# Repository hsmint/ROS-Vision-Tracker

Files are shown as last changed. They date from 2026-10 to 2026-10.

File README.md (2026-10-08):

<div align="center">

# ROS-Vision-Tracker

### See the cube. Follow the motion.

A depth-aware, two-axis camera tracker built with ROS 2 and Raspberry Pi.

**KANT PA 1기 · Project 1 · Team Xmen**






**[Quick start](#quick-start)** · **[Architecture](#architecture)** · **[Demo](#demo)** · **[Performance](#performance-snapshot)** · **[Documentation](#documentation)** · **[Releases](https://github.com/hsmint/ROS-Vision-Tracker/releases)**

</div>

---

ROS-Vision-Tracker finds a blue cube and keeps it in view. An Intel RealSense camera captures
color and aligned depth on a Raspberry Pi; the tracker checks color, physical
size, and shape, then bridges brief occlusions with CSRT. An OpenCR board drives
two DYNAMIXEL servos to aim the camera. An optional remote PC displays the
annotated image and robot model in RViz2.

## Highlights

| 🔎 Depth-aware detection | 🎯 Pan & tilt tracking | 🖥️ Remote visualization |
| :--- | :--- | :--- |
| HSV color, real-world size, and shape checks help select the blue cube. | Independent velocity commands drive two axes, with automatic homing on startup. | Annotated JPEG preview and an RViz2 robot model keep tracking visible from a second machine. |

| 🧩 Occlusion handling | 📼 Record & replay | 🍓 Runs on the Pi |
| :--- | :--- | :--- |
| CSRT bridges brief gaps in detection. | Replay synchronized color and depth bags for offline analysis. | Capture, tracking, and control continue without a remote PC. |

## Architecture

```mermaid
flowchart LR
    subgraph PI["Raspberry Pi · ROS 2"]
        CAMERA["RealSense capture"]
        TRACKER["Cube detector + tracker"]
        CONTROL["OpenCR serial driver"]
        PREVIEW["JPEG preview"]
        CAMERA -->|"RGB + aligned depth"| TRACKER
        TRACKER -->|"/cmd_vel"| CONTROL
        CAMERA -->|"Color frames"| PREVIEW
        TRACKER -->|"/tracking/bbox"| PREVIEW
    end

    CONTROL -->|"Serial"| OPENCR["OpenCR"]
    OPENCR --> MOTORS["DYNAMIXEL · pan + tilt"]
    PREVIEW -->|"Annotated JPEG"| PC["Remote PC · RViz2"]

    classDef vision fill:#e0f2fe,stroke:#0284c7,color:#0c4a6e
    classDef motion fill:#dcfce7,stroke:#16a34a,color:#14532d
    classDef display fill:#f3e8ff,stroke:#9333ea,color:#581c87
    class CAMERA,TRACKER vision
    class CONTROL,OPENCR,MOTORS motion
    class PREVIEW,PC display
```

The default launch targets **30 Hz image publication**, **20 Hz tracking**, and
**20 Hz commands**. The separate JPEG preview targets **5 Hz**. These are
configured rates; see [Performance](#performance-snapshot) for measured performance and limits.

| Package | Responsibility |
| :--- | :--- |
| [`xmen_tracker`](xmen_tracker/) | RealSense capture, cube detection/tracking, velocity commands, JPEG preview, RViz overlays |
| [`xmen_control`](xmen_control/) | OpenCR serial driver (`control_lite`) and `/joint_states` publication |
| [`xmen_bringup`](xmen_bringup/) | Hardware and remote visualization launch files |
| [`xmen_description`](xmen_description/) | Pan/tilt URDF, CAD meshes, and RViz configuration |
| [`firmware`](firmware/) | OpenCR source and prebuilt ARM64 flashing bundle |

## Demo

<div align="center">

### 🎬 See ROS-Vision-Tracker in action

</div>

#### 🎯 Real-world tracking

https://github.com/user-attachments/assets/06dc1db3-719f-4d2d-9c7e-61715f263b9c

#### 🖥️ Inside RViz2

https://github.com/user-attachments/assets/06f8cf11-2dbd-4d1b-b99b-0d997ce7b2b6

## Prerequisites

### Hardware

- Raspberry Pi running **64-bit Ubuntu 26.04 (ARM64)**
- Intel RealSense depth camera (D435 or similar), connected over USB 3
- ROBOTIS OpenCR 1.0 with two DYNAMIXEL XM430-W350 servos (pan ID 11, tilt ID 12)
- A blue cube target (about 5 cm)
- Optional: a PC on the same network for RViz2 visualization

### Software

- [ROS 2 Lyrical](https://docs.ros.org/en/lyrical/Installation/Ubuntu-Install-Debs.html), installed at `/opt/ros/lyrical`
- [RealSense SDK Python bindings (`pyrealsense2`)](https://github.com/realsenseai/librealsense)
  for the system Python, plus its USB rules. rosdep does not install this one; see
  [camera package](xmen_tracker/).
- Serial port access for your user (for flashing and for `control_lite`):

  ```bash
  sudo usermod -aG dialout $USER   # then log out and back in
  ```

### Firmware

The prebuilt firmware in [`firmware/opencr.tar.gz`](firmware/opencr.tar.gz)
needs no extra tools. Its flasher, `opencr_ld`, is an ARM64 Linux binary that
only depends on the C library, so it runs on the Pi as is. Flashing from an
x86 PC is not supported with this archive.

Only if you change [`opencr_lite.ino`](firmware/opencr_lite.ino): Arduino IDE
with the [OpenCR board package](https://emanual.robotis.com/docs/en/parts/controller/opencr10/#arduino-ide)
and the `Dynamixel2Arduino` library.

<details>
<summary><strong>Package dependency reference</strong></summary>

These are declared in each `package.xml`; `rosdep` installs them.

| Package | Dependencies |
|---|---|
| `xmen_tracker` | `rclpy`, `sensor_msgs`, `geometry_msgs`, `std_msgs`, `visualization_msgs`, `message_filters`, `cv_bridge`, `tf2_ros_py`, `rcl_interfaces`, `launch`, `launch_ros`, `python3-numpy`, `python3-opencv`, `python3-yaml` |
| `xmen_control` | `rclpy`, `geometry_msgs`, `sensor_msgs`, `python3-serial`, `dynamixel_sdk` |
| `xmen_bringup` | `launch`, `launch_ros`, `rviz2`, `robot_state_publisher`, `joint_state_publisher`, `tf2_ros`, `ros2bag`, `rosbag2_transport`, `rosbag2_storage_default_plugins` |
| `xmen_description` | none (URDF and meshes only) |

</details>

## Quick start

### 1 · Flash the OpenCR

[`firmware/opencr.tar.gz`](firmware/opencr.tar.gz) contains the prebuilt
firmware (`opencr_lite.opencr`) and the flasher (`opencr_ld`, built for ARM64,
so run it on the Pi). Connect the OpenCR over USB, then find its port:

```bash
ls /dev/ttyACM*            # usually /dev/ttyACM0
```

Extract the archive and flash the firmware:

```bash
# From the repository root on the Pi
cd firmware
tar -xf opencr.tar.gz
PORT=/dev/ttyACM0          # the port found above
./opencr_ld $PORT 115200 opencr_lite.opencr
```

If the port gives "permission denied", check the `dialout` prerequisite above.

`control_lite` only works with this firmware. To change it, edit
[`firmware/opencr_lite.ino`](firmware/opencr_lite.ino) and rebuild it in the
Arduino IDE.

### 2 · Set up the Raspberry Pi

Option A uses a prebuilt release and needs no build. Option B builds from source.

<details open>
<summary><strong>Option A · Install a prebuilt release</strong></summary>

Download the `.tar.gz` and `.sha256` from
[Releases](https://github.com/hsmint/ROS-Vision-Tracker/releases):

```bash
# Replace v1.0.0 with the downloaded release version.
sha256sum -c xmen-v1.0.0-ubuntu-26.04-ros-lyrical-arm64.tar.gz.sha256
mkdir -p ~/xmen-v1.0.0
tar -xzf xmen-v1.0.0-ubuntu-26.04-ros-lyrical-arm64.tar.gz -C ~/xmen-v1.0.0
cd ~/xmen-v1.0.0

# One-time: install ROS/system dependencies
sudo apt-get install python3-rosdep
sudo rosdep init   # only if rosdep is not initialized yet
rosdep update --rosdistro lyrical
rosdep install --from-paths dependencies --ignore-src --rosdistro lyrical -y

. install/setup.bash
python3 check-runtime.py   # checks imports; does not open the camera or move motors
```

Extract each new release into a fresh directory to avoid stale files.

</details>

<details>
<summary><strong>Option B · Build from source</strong></summary>

```bash
mkdir -p ~/xmen_ws/src && cd ~/xmen_ws/src
git clone https://github.com/hsmint/ROS-Vision-Tracker.git Xmen
cd ~/xmen_ws
source /opt/ros/lyrical/setup.bash
rosdep install --from-paths src --ignore-src -r -y
colcon build --symlink-install --packages-up-to xmen_bringup
source install/setup.bash
```

</details>

### 3 · Start tracking

On the **Pi**:

```bash
export ROS_DOMAIN_ID=50   # use the same value on both machines
ros2 launch xmen_bringup hardware_launch.py
```

> [!IMPORTANT]
> The motors home on startup, then the camera follows the cube. Use
> `start_control:=false` to run the camera and tracker without moving the motors.

Useful options:

```bash
ros2 launch xmen_bringup hardware_launch.py port:=/dev/ttyACM0      # choose a serial port
ros2 launch xmen_bringup hardware_launch.py start_control:=false   # track without moving motors
ros2 launch xmen_bringup hardware_launch.py image_hz:=15.0         # lower CPU load
```

On the **remote PC** (optional, build from source as in 2B):

```bash
export ROS_DOMAIN_ID=50   # use the same value on both machines
ros2 launch xmen_bringup rviz2_launch.py
```

Both machines must use the same `ROS_DOMAIN_ID` and be able to reach each other
over the network. Tracking keeps running without the PC.

Check the tracker from either machine:

```bash
ros2 topic echo /perception_status   # OK, NO_TARGET, or CAMERA_STALL
ros2 topic echo /target --qos-reliability best_effort
```

To record and replay rosbags, use the RViz options, or set serial-port
overrides, see the [bringup package](xmen_bringup/). To tune
detection, see [xmen_tracker](xmen_tracker/) and
[PERCEPTION.md](lv2_module5/results/PERCEPTION.md).

## Documentation

| I want to… | Read this |
| :--- | :--- |
| Configure launch options, remote RViz, or bag playback | [Bringup package](xmen_bringup/) |
| Understand tracker nodes, topics, and commands | [Tracker package](xmen_tracker/) |
| Tune detection or evaluate recordings | [Perception guide](lv2_module5/results/PERCEPTION.md) |
| Set up the camera and Python bindings | [Camera package](xmen_tracker/) |
| Inspect the robot model and meshes | [Robot description](xmen_description/) |
| Modify the OpenCR firmware | [Firmware source](firmware/opencr_lite.ino) |

## Performance Snapshot

**Raspberry Pi 4** · 640×360 RGB + depth · 60-second sample

| 📷 RGB / Depth | 🎯 Tracking | ⚙️ Commands | 🖥️ Preview |
| :---: | :---: | :---: | :---: |
| **25.85 / 25.86 FPS** | **12.66 Hz** | **13.59 Hz** | **2.00 FPS** |

**Tracker status:** `OK` throughout the sample

## Contributors

<div align="center">

### Team Xmen

ROS-Vision-Tracker was developed as **Project 1 for KANT PA 1기**.

<table>
  <tr>
    <td align="center" width="25%">
      <a href="https://github.com/hsmint">
        SeokMin Hong GitHub profile
      </a>
      <br /><br />
      <strong>SeokMin Hong</strong>
      <br />
      <a href="https://github.com/hsmint">@hsmint</a>
    </td>
    <td align="center" width="25%">
      <a href="https://github.com/chj1319">
        최형준 GitHub profile
      </a>
      <br /><br />
      <strong>최형준</strong>
      <br />
      <a href="https://github.com/chj1319">@chj1319</a>
    </td>
    <td align="center" width="25%">
      <a href="https://github.com/heffeekim94-web">
        김혜민 GitHub profile
      </a>
      <br /><br />
      <strong>김혜민</strong>
      <br />
      <a href="https://github.com/heffeekim94-web">@heffeekim94-web</a>
    </td>
    <td align="center" width="25%">
      <a href="https://github.com/kanichong">
        이홍주 GitHub profile
      </a>
      <br /><br />
      <strong>이홍주</strong>
      <br />
      <a href="https://github.com/kanichong">@kanichong</a>
    </td>
  </tr>
</table>

</div>

---

<div align="center">

**[Get started](#quick-start)** · **[Explore the docs](#documentation)** · **[Back to top](#ros-vision-tracker)**

</div>

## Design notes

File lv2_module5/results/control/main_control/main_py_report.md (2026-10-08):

# main.py 코드 설명 보고서

2026-10-03 · pa06

## 개요

main.py는 라즈베리파이에서 키보드로 입력한 명령을 USB 시리얼로 OpenCR 보드에 보내고, 보드가 보낸 답을 화면에 출력하는 63줄짜리 프로그램입니다. 모터를 직접 움직이지는 않습니다. 명령 해석, 범위 검사, 모터 제어는 모두 OpenCR 펌웨어(opencr_control.ino)가 맡습니다.

프로그램은 두 방향의 데이터를 동시에 처리합니다.
- **보내는 방향:** 키보드 입력 → `send_command()` → USB → OpenCR
- **받는 방향:** OpenCR의 `Serial.println()` → USB → 반복 루프의 수신 부분 → 화면

두 방향을 하나의 반복문에서 번갈아 확인할 수 있는 이유는 `select`가 키보드와 보드 중 데이터가 도착한 쪽을 알려 주기 때문입니다. 그래서 모터가 움직이는 동안에도 보드 메시지를 계속 보여 주면서 새 명령(예: `x` 정지)을 받을 수 있습니다.

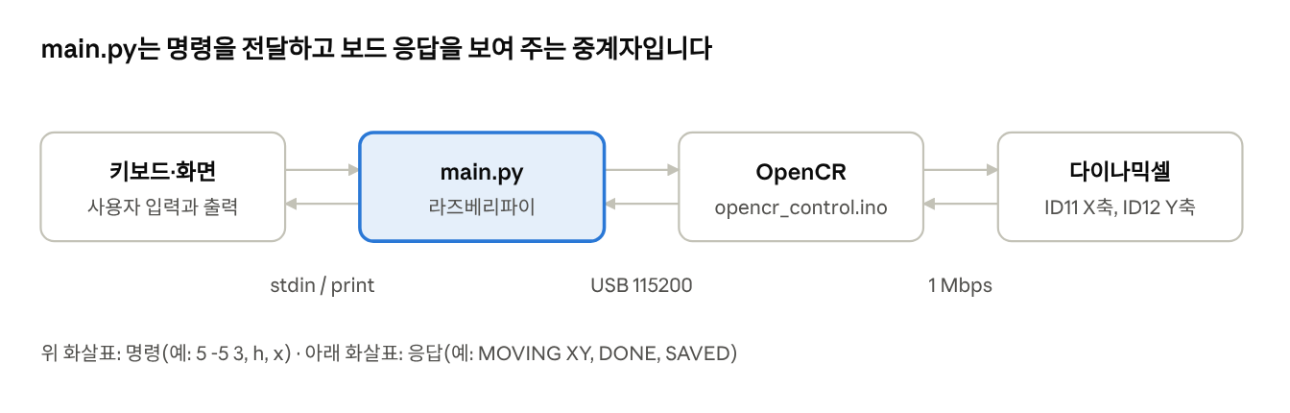
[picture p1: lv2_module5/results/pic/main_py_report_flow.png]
데이터 흐름 · 4단계, 양방향


*데이터 흐름 · 4단계, 양방향*

명령은 왼쪽에서 오른쪽으로, 응답은 오른쪽에서 왼쪽으로 흐릅니다. main.py는 가운데에서 글자를 전달만 합니다.

## 1~13줄: 준비물과 설정값

파일 맨 위에서 필요한 도구를 불러오고, 통신 설정과 사용법 안내문을 정합니다.

| 줄 | 코드 | 뜻 |
|---|---|---|
| 1 | `"""..."""` | 파일 설명문입니다. 실행에는 영향이 없습니다. |
| 2 | `import select` | 키보드와 보드 중 어느 쪽에 새 데이터가 왔는지 동시에 지켜보는 도구입니다. |
| 3 | `import sys` | 키보드 입력(`sys.stdin`), 오류 출력, 프로그램 종료에 씁니다. |
| 4 | `import time` | 기다리기(`time.sleep`)에 씁니다. |
| 6 | `import serial` | USB 시리얼 통신 라이브러리(pyserial)입니다. OpenCR과 대화하는 데 씁니다. |
| 8 | `PORT = "/dev/ttyACM0"` | OpenCR이 연결된 USB 장치 이름입니다. |
| 9 | `BAUDRATE = 115200` | 통신 속도입니다. 펌웨어의 `Serial.begin(115200)`과 반드시 같아야 합니다. |
| 10~13 | `HELP = """..."""` | 사용법 안내문입니다. 시작할 때와 `help`를 입력했을 때 출력됩니다. |

`import serial`만 빈 줄로 떨어져 있는 이유는 파이썬 관례 때문입니다. 기본 내장 모듈(select, sys, time)과 따로 설치한 모듈(serial)을 나눠 적습니다.

## 16~18줄: send_command(), 보드로 명령 보내기

입력한 글자를 보드가 알아듣는 형식으로 바꿔 한 줄 단위로 보냅니다.

```python
def send_command(board, command):
    board.write((command.strip() + "\n").encode("ascii"))
    board.flush()
```

- **16줄:** `board`는 열려 있는 시리얼 포트, `command`는 보낼 글자입니다.
- **17줄:** 세 단계를 한 줄에서 처리합니다.
  - `strip()`: 앞뒤 공백을 지웁니다.
  - `+ "\n"`: 끝에 줄바꿈을 붙입니다. OpenCR은 줄바꿈을 받아야 명령 한 줄이 끝났다고 판단합니다.
  - `encode("ascii")`: 글자를 바이트로 바꿉니다. 한글처럼 ASCII가 아닌 글자가 있으면 `UnicodeEncodeError`가 납니다.
- **18줄:** `flush()`로 모아 둔 데이터를 즉시 내보냅니다.

## 21~27줄: main() 연결 준비

포트를 열고 보드가 준비될 때까지 기다린 뒤, 사용법을 보여 주는 단계입니다.

| 줄 | 코드 | 뜻 |
|---|---|---|
| 21 | `def main():` | 프로그램 본체 함수입니다. |
| 22 | `with serial.Serial(...) as board:` | 시리얼 포트를 엽니다. `with`를 쓰면 프로그램이 끝날 때 포트가 자동으로 닫힙니다. |
| 22 | `timeout=0.1` | 읽을 때 최대 0.1초만 기다립니다. |
| 22 | `write_timeout=2` | 보낼 때 2초 안에 못 보내면 오류로 처리합니다. |
| 23 | `time.sleep(2)` | 2초 기다립니다. 포트를 열면 OpenCR이 재시작될 수 있어 준비 시간을 줍니다. |
| 24~25 | `send_command(board, "")` | 빈 줄을 보내 보드에 반쯤 남아 있던 입력을 끊어 줍니다. |
| 26 | `print(HELP, flush=True)` | 사용법을 출력합니다. `flush=True`는 화면에 바로 표시하라는 뜻입니다. |
| 27 | `pending = bytearray()` | 보드에서 받은 바이트를 한 줄이 완성될 때까지 모아 두는 상자입니다. |

## 29~49줄: 반복 루프

프로그램이 켜져 있는 동안 이 부분을 계속 반복합니다. 한 번 도는 동안 보드 수신과 키보드 입력을 차례로 확인합니다.

### 기다리기 (28~30줄)
- **28줄 `try:`** 아래에서 오류나 Ctrl+C가 생겨도 50줄 이후의 종료 처리로 가게 합니다.
- **29줄 `while True:`** 무한 반복입니다. `break`를 만나야 끝납니다.
- **30줄 `select.select([sys.stdin, board], [], [], 0.2)`** 키보드와 보드를 최대 0.2초 동안 함께 지켜봅니다. 데이터가 온 쪽이 `readable` 목록에 담깁니다. 아무것도 오지 않으면 빈 목록으로 다시 반복합니다.

### 보드에서 데이터가 왔을 때 (31~37줄)

| 줄 | 코드 | 뜻 |
|---|---|---|
| 31 | `if board in readable:` | 보드에서 새 데이터가 왔을 때만 실행합니다. |
| 32 | `board.read(board.in_waiting or 1)` | 도착한 바이트를 모두 읽어 `pending`에 붙입니다. 도착한 수를 모르면 1바이트만 읽습니다. |
| 33 | `while b"\n" in pending:` | 줄바꿈이 있는 동안, 완성된 줄을 하나씩 꺼냅니다. |
| 34 | `pending.partition(b"\n")` | 첫 줄바꿈 앞(`line`)과 뒤(남은 `pending`)로 나눕니다. |
| 35 | `decode("utf-8", errors="replace")` | 바이트를 글자로 바꿉니다. 깨진 바이트는 대체 기호로 바꿔 프로그램이 멈추지 않게 합니다. |
| 36~37 | `if message: print(...)` | 빈 줄이 아니면 화면에 출력합니다. `MOVING XY`, `DONE`, `SAVED` 같은 보드 메시지가 여기서 보입니다. |

### 키보드 입력이 왔을 때 (38~49줄)

| 줄 | 코드 | 뜻 |
|---|---|---|
| 38 | `if sys.stdin in readable:` | 키보드에서 Enter가 눌렸을 때만 실행합니다. |
| 39 | `sys.stdin.readline()` | 입력한 한 줄을 읽습니다. |
| 40~41 | `if not line or ... == "q": break` | 입력이 끝났거나(Ctrl+D) `q`면 반복을 끝냅니다. |
| 42 | `command = line.strip()` | 앞뒤 공백과 줄바꿈을 지웁니다. |
| 43~44 | `if command == "help":` | 보드에 보내지 않고 사용법만 출력합니다. |
| 45~47 | `elif command: send_command(...)` | 빈 줄이 아닌 나머지 명령은 모두 보드로 보냅니다. 명령이 맞는지는 보드가 판단합니다. |
| 48~49 | `except UnicodeEncodeError:` | 한글처럼 ASCII가 아닌 글자를 입력하면 프로그램이 멈추지 않게 안내만 출력합니다. |

## 50~55줄: 종료 처리

어떻게 끝나든 보드에 정지 명령 `x`를 보내, 프로그램을 꺼도 모터가 계속 움직이지 않게 하는 안전장치입니다.

| 줄 | 코드 | 뜻 |
|---|---|---|
| 50~51 | `except KeyboardInterrupt: pass` | Ctrl+C를 눌러도 오류 메시지 없이 조용히 넘어갑니다. |
| 52 | `finally:` | `q`, Ctrl+C, 오류 중 어떤 이유로 끝나든 반드시 실행됩니다. |
| 54 | `send_command(board, "x")` | 보드에 정지 명령을 보냅니다. 펌웨어 V2에서는 이때 현재 위치가 EEPROM에 저장됩니다. |
| 55 | `print("정지 명령 전송, 종료.")` | 종료 사실을 화면에 알립니다. |

이 부분이 끝나면 22줄 `with` 블록을 빠져나면서 시리얼 포트가 자동으로 닫힙니다.

## 58~63줄: 프로그램 시작점

`python3 main.py`로 실행하면 여기서부터 시작합니다. USB 연결 문제를 알기 쉬운 한 줄짜리 메시지로 바꿔 줍니다.

| 줄 | 코드 | 뜻 |
|---|---|---|
| 58 | `if __name__ == "__main__":` | 이 파일을 직접 실행했을 때만 아래를 실행합니다. 다른 파일에서 `import`하면 실행되지 않습니다. |
| 60 | `main()` | 프로그램 본체를 실행합니다. |
| 61 | `except (serial.SerialException, OSError)` | 포트를 찾지 못했거나, 다른 프로그램(시리얼 모니터 등)이 쓰고 있거나, USB가 빠진 경우입니다. |
| 62 | `print(..., file=sys.stderr)` | `시리얼 연결 오류: ...`를 오류 출력으로 내보냅니다. |
| 63 | `sys.exit(1)` | 종료 코드 1(실패)로 끝냅니다. |

## 명령 요약

main.py가 직접 처리하는 명령은 `help`와 `q` 두 개뿐입니다. 나머지는 그대로 보드로 전달됩니다.

| 입력 | 처리하는 곳 | 동작 |
|---|---|---|
| `5 -5 3` | OpenCR | 현재 위치 기준 X +5°, Y -5°를 3°/s로 이동 |
| `h` | OpenCR | Y축부터 X축 순서로 30°/s 홈 복귀 |
| `x` | OpenCR | 정지, 위치 유지, 위치 저장 |
| `off` | OpenCR | 토크 해제. 카메라를 지지한 상태에서 사용 |
| `p` | OpenCR | 펌웨어 버전, 저장 위치, 현재 위치·토크·오류 출력 |
| `scan` | OpenCR | ID11·ID12 모터 상태 조회 |
| `auto on` / `auto off` | OpenCR | 보드 시작 시 홈 복귀 / 저장 위치 복원 설정 |
| `help` | main.py | 사용법 다시 출력 |
| `q` 또는 Ctrl+C | main.py | 보드에 `x`를 보낸 뒤 종료 |

실행 명령은 `python3 /home/pa06/main.py`입니다. 실행 전에 시리얼 모니터를 꺼야 포트 충돌이 없습니다.

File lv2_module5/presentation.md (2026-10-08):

# Xmen 추적 카메라

> ROS 2 기반 2축 비전 추적 시스템

## 목차

| 순서 | 주제 |
| :---: | :--- |
| 1부 | 문제 정의와 시스템 구성 |
| 2부 | 인지와 제어 |
| 3부 | 결과와 배운 점 |

---

# 1부. 문제 정의와 시스템 구성

## 파란 큐브를 스스로 따라보는 CCTV형 2축 카메라

**과제 정의**

- **RealSense D435**가 본 파란 큐브를 화면 중앙으로 끌어오는 것이 목표
- 목표물은 **30×30×60 mm** 파란 직육면체 하나 — 거리 **0.2~1.0 m**에서 찾아야 한다
- 조명은 어두움 · 보통 · 밝음 세 조건 모두에서 같은 설정으로 동작해야 한다
- 비슷한 색의 다른 물체(의자 · 카펫 · 파란 브래킷)를 목표로 오인하면 안 된다
- 사람이 큐브를 들고 움직이거나 손에 반쯤 가려져도 계속 따라가야 한다

## 목표 사양

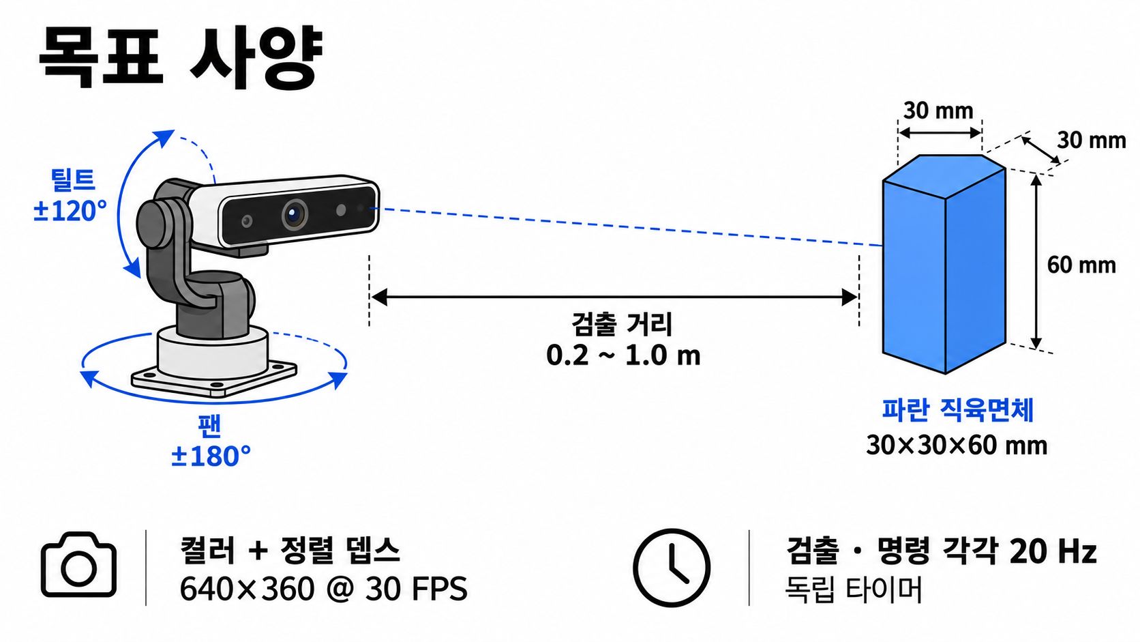
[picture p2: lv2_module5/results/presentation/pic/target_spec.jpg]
목표 사양


| # | 항목 | 사양 | 비고 |
| :---: | :--- | :--- | :--- |
| 1 | 검출 거리 | 0.2 ~ 1.0 m | 실측 Z 2.01~1.03 m |
| 2 | 목표물 | 30×30×60 mm | 파란 직육면체 |
| 3 | 영상 | 640×360 @ 30 FPS | 컬러 + 정렬 뎁스 |
| 4 | 검출 · 명령 주기 | 각각 20 Hz | 독립 타이머 |
| 5 | 구동 범위 | ±180° / ±40° | 팬 / 틸트 |

## 하드웨어 구성

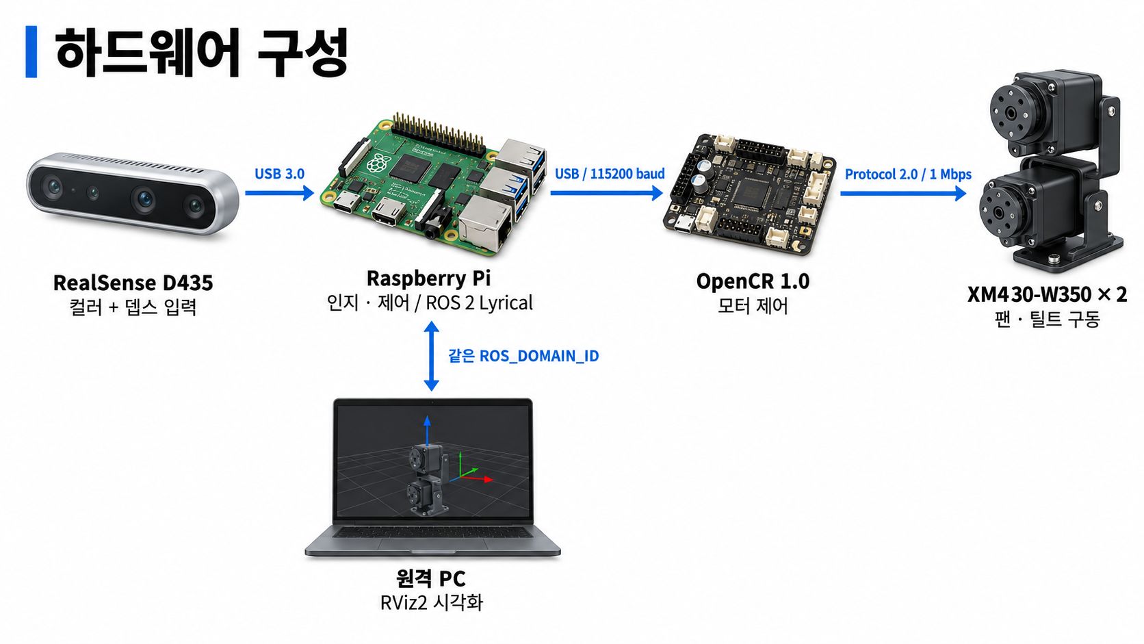
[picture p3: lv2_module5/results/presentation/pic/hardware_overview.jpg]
하드웨어 구성


| # | 장치 | 역할 | 연결 |
| :---: | :--- | :--- | :--- |
| 1 | RealSense D435 | 컬러 + 뎁스 입력 | USB 3.0 |
| 2 | Raspberry Pi | 인지 · 제어 전부 | ROS 2 Lyrical |
| 3 | OpenCR 1.0 | 모터 제어 보드 | USB 115200 baud |
| 4 | XM430-W350 × 2 | 팬 · 틸트 구동 | Protocol 2.0, 1 Mbps |
| 5 | 원격 PC | RViz2 시각화 | 같은 ROS_DOMAIN_ID |

## 지켜야 했던 다섯 가지 설계 기준

- **최신성** — 늦게 도착한 프레임보다 다음 프레임이 낫다.
- **일정 주기** — 영상이 끊겨도 명령 타이머는 20 Hz로 계속 0을 내보낸다
- **안전 우선** — 어느 단계가 끊겨도 모터는 반드시 선다.
- **재현성** — 튜닝 값은 코드가 아니라 YAML에 둔다. 재빌드 없이 바꾼다
- **원격 분리** — 네트워크가 느려도 추적 주기는 영향을 받지 않는다

## 노드 그래프 — 실제로 돌고 있는 연결

`realsense_node` → `tracker_node` → `control_lite`, 그리고 `preview_node`

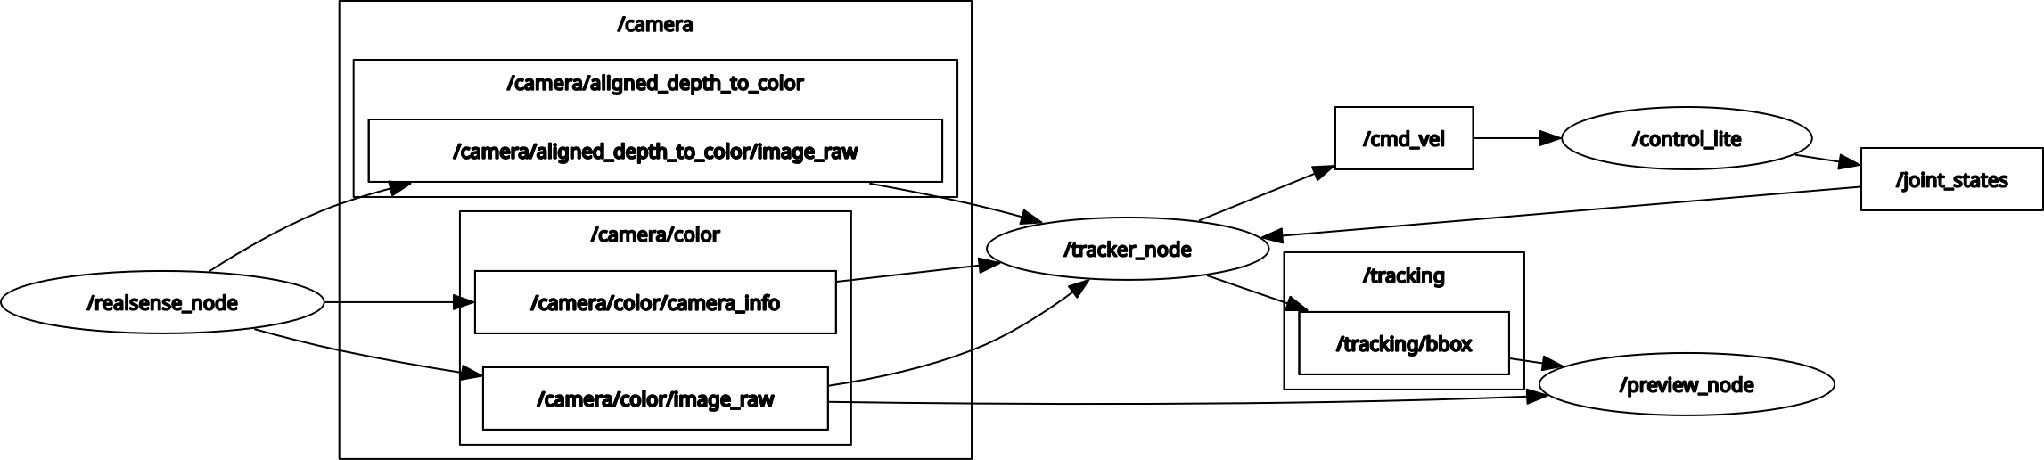
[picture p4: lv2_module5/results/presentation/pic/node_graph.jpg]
노드 그래프


## 패키지 다섯 개, 역할 하나씩

| # | 패키지 | 역할 | 대표 노드/파일 |
| :---: | :--- | :--- | :--- |
| 1 | `xmen_vision` | 카메라 입력 | `realsense_node` |
| 2 | `xmen_tracker` | 검출 + 추종 제어 | `tracker_node` |
| 3 | `xmen_control` | 모터 시리얼 구동 | `control_lite` |
| 4 | `xmen_description` | URDF · RViz 모델 | `cctv.urdf` |
| 5 | `xmen_bringup` | 런치 · 파라미터 | `hardware_launch.py` |

## 토픽 다섯 개로 전부 연결된다

| # | 토픽 | 내용 | QoS · 주기 |
| :---: | :--- | :--- | :--- |
| 1 | `/camera/color/image_raw` | 컬러 + 정렬 뎁스 | reliable · 30 Hz |
| 2 | `/target` | 중심 오차 · 면적비 | best-effort · 20 Hz |
| 3 | `/cmd_vel` | 팬 · 틸트 각속도 | reliable · 20 Hz |
| 4 | `/tracking/bbox` | 같은 프레임 검출 박스 | reliable · depth 10 |
| 5 | `/joint_states` | 측정된 관절 각도 | reliable · 100 Hz |

---

# 2부. 인지와 제어

## 검출은 다섯 단계를 순서대로 통과한다

| 단계 | 검사 | 기준 |
| :---: | :--- | :--- |
| ① | 색 마스크 | HSV + 최소 채도 |
| ② | 면적 | 픽셀 하한 · 상한 |
| ③ | 모양 | 장단비 · 채움비 |
| ④ | 상자 판정 | box_fit 다각형 근사 |
| ⑤ | 뎁스 검증 | 거리 · 실제 크기 |

## 뎁스로 픽셀을 센티미터로 바꾼다

**뎁스 검증**

- 컨투어 안 뎁스의 중앙값 Z를 쓴다 — 경계 화소는 1회 침식으로 제외한다
- 핀홀 모형: `실제 길이 = 픽셀 길이 × Z / f`. 회전에 무관하게 외접사각형 변을 쓴다
- 기준은 짧은 변 ≤ 6 cm, 긴 변 ≤ 8 cm, 실제 넓이 3~30 cm², 거리 0.1~1.1 m
- 초점거리는 `camera_info`가 오면 실제 값으로 바꾸고 면적 기준을 다시 계산한다
- 너무 가까워 뎁스가 없으면 800 px 이상일 때만 색과 크기만으로 통과시킨다

## 제어 — 오차 하나를 각속도로 바꾼다

**`tracker_node` / 추종 제어**

- `명령 = clamp(sign × Kp × 정규화 오차, ±max)` — P 제어 하나로 끝낸다
- |오차| < 데드밴드 0.05면 0 — 중앙 근처에서 좌우로 떠는 것을 막는다
- 팬은 `angular.z`, 틸트는 `angular.y`. 나머지 성분은 항상 0이다
- REP-103을 따른다 — `angular.z` + = 왼쪽, `angular.y` + = 아래
- 각도가 아니라 각속도다 — 모터 드라이버가 위치로 적분하지 않는다

## control_lite — 100 Hz로 시리얼을 지킨다

**`xmen_control` / `control_lite`**

- `/cmd_vel`을 받아 `'v 팬 틸트'` 한 줄을 보내고, `'p'`로 현재 위치를 되묻는다
- 10 ms 주기 타이머가 수신 버퍼를 읽어 줄 단위로 끊고 해석한다
- 받은 엔코더 틱을 라디안으로 바꿔 `/joint_states`에 pan · tilt로 발행한다
- 0.2 s 동안 새 명령이 없으면 0을 보낸다 — 지난 Twist는 절대 재사용하지 않는다
- 포트는 exclusive로 연다 — 다른 프로세스가 같은 포트를 잡지 못하게 한다

## 시작할 때 반드시 원점을 잡고 들어간다

**`control_lite` / 홈 시퀀스**

- 틸트를 먼저, 그다음 팬 — 두 축을 동시에 움직이지 않는다
- 4틱 이내까지 접근한 뒤, 8틱 밴드 안에서 0.2 s 머물러야 도착으로 본다
- 좁은 밴드로 들어가 넓은 밴드로 판정해 경계에서 떠는 것을 막는다
- 한 축을 맞추는 사이 다른 축이 8틱 밖으로 밀리면 최대 3번까지 다시 한다
- 30초 안에 못 맞추면 시작 · 최근접 위치와 마지막 명령을 남기고 멈춘다

---

# 3부. 결과와 배운 점

## 끊기는 지점마다 정지 규칙을 뒀다

| # | 구간 | 조건 | 동작 |
| :---: | :--- | :--- | :--- |
| 1 | 카메라 → 검출 | 0.5 s 영상 없음 | `CAMERA_STALL` |
| 2 | 검출 → 제어 | 0.5 s 입력 없음 | 두 축 0 발행 |
| 3 | 제어 → 모터 | 0.2 s 명령 없음 | `'v 0 0'` 전송 |
| 4 | Pi → OpenCR | 모터 워치독 200 ms | 모터 자체 정지 |
| 5 | 노드 종료 | 종료 직전 0 발행 | shutdown 처리 |

## 원격 PC로 원본 영상을 보내지 않는다

**`preview_node`**

- 640×360 컬러 30 Hz 원본은 초당 약 21 MB — 흘리면 추적까지 같이 느려진다
- Pi에서 박스를 그린 뒤 JPEG 품질 70으로 5 Hz만 내보낸다
- 구독자가 하나도 없으면 인코딩 자체를 하지 않는다
- 영상과 박스는 타임스탬프가 정확히 맞는 짝만 보낸다 — 옛 박스를 덧그리지 않는다
- 원본 RGB · 뎁스는 Pi 안에 남고, 검출 · 명령은 20 Hz 그대로다

## RViz2에서 로봇과 목표를 함께 본다

**`xmen_description` / `rviz_node`**

- Onshape에서 뽑은 URDF와 STL로 CCTV 본체를 RobotModel로 띄운다
- `camera_link`는 CAD 카메라 하우징 +Y 면에 붙어 팬 · 틸트를 따라 움직인다
- 주석이 그려진 영상을 `camera_link` 앞 0.25 m에 폭 0.4 m 평면으로 세운다
- 목표 마커는 `tracking_image` 프레임에 고정돼 카메라와 함께 돈다
- 이건 표시용 좌표계다 — 실제 작업 공간의 측정 위치가 아니다

## 튜닝과 평가를 명령 하나로 돌린다

**`target_perception` / tuning · evaluate**

- **tune** — 화면에서 드래그하면 그 화소로 HSV 범위를 제안하고 트랙바로 다듬는다
- **collect** — 조명 · 거리 라벨을 붙여 컬러 + 뎁스를 30장씩 데이터셋으로 모은다
- **bench** — 조건별 100프레임의 검출률 · Z · 처리 시간을 측정한다
- **evaluate** — 저장된 뎁스로 노드와 같은 검증까지 돌려 설정 A · B를 비교한다
- 결과는 조명×거리 인식률 표와 조건별 몽타주 이미지로 남는다

## 정리

> 색으로 찾고, 뎁스로 확인하고, 오차 하나로 움직인다
>
> 끊길 수 있는 모든 지점에 정지 규칙을 걸었다

ROS 2 Lyrical · RealSense D435 · OpenCR · XM430-W350 × 2

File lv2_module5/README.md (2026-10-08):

# Xmen — ROS-Vision-Tracker

RealSense D435와 OpenCR·Dynamixel을 활용한 ROS 2 기반 2축 비전 추적 프로젝트의 보고서와 실험 산출물입니다. 파란 큐브 검출, 중심 오차 기반 제어, 목표 소실 복구 및 bag 재현 결과를 정리합니다.

## 디렉터리 구조

아래 구조는 주요 파일과 폴더를 요약한 것입니다. 반복되는 실험 파일과 이미지 목록은 생략했습니다.

```text
lv2_module5/
├── README.md                         # 프로젝트 구조와 문서 안내
├── report.md                         # 전체 과제 보고서 (문제 1~5, 심화)
├── presentation.md                   # 발표 원고
├── team.md                           # 팀 구성, 역할 및 기여
└── results/
    ├── PERCEPTION.md                 # 인지 튜닝·평가 안내
    ├── answer/                       # 문제별 상세 보고서와 증빙
    │   ├── problem1/
    │   │   ├── report_problem1.md     # 색 기반 검출 결과
    │   │   └── capture/              # 원본·마스크·오버레이 이미지
    │   ├── problem3/
    │   │   ├── report_problem3.md     # P 제어와 Kp 비교
    │   │   ├── gif/                  # 추적 영상
    │   │   └── pic/                  # 제어 흐름 및 결과 그래프
    │   ├── problem4/
    │   │   ├── report_problem4.md     # 성능 측정·소실 복구·정지 시험
    │   │   ├── frames/               # 평가 프레임 및 CSV 기록
    │   │   ├── gif/                  # 시험별 동작 영상
    │   │   └── pic/                  # 상태 흐름 및 결과 그래프
    │   └── problem5/
    │       ├── report_problem5.md     # bag 재현 및 협업 검증
    │       ├── third_party_log.txt    # 다른 팀원의 실행 로그
    │       └── pic/                  # 재현 결과 캡처
    ├── bags/                         # ROS 2 bag 및 분석 결과
    │   ├── kp*_run*/                 # Kp별 반복 실험 (MCAP·metadata.yaml)
    │   ├── p4_ctrl/                  # 제어 통신 중단 시험
    │   ├── p4_input/                 # 인지 입력 중단 시험
    │   ├── p4_normal/                # 정상 추적 시험
    │   ├── p4_occl/                  # 가림·재등장 시험
    │   ├── csv/                      # 시계열 CSV·JSON 및 요약 지표
    │   └── plots/                    # 실험 그래프 및 요약 CSV
    ├── bringup/
    │   ├── TOPICS.md                 # 노드·토픽·QoS·인터페이스 규약
    │   └── parameter.md              # 설정 파라미터 설명
    ├── control/
    │   ├── opencr_control_report.md  # OpenCR 제어 설명
    │   ├── opencr_control_flow.drawio # 편집 가능한 제어 흐름도
    │   ├── opencr_lite_*.png          # 펌웨어 구조·루프·설정 이미지
    │   └── main_control/
    │       ├── main.py               # 제어 Python 코드
    │       └── main_py_report.md      # 코드 설명
    ├── pic/                          # 시스템 및 제어 설명 이미지
    └── presentation/
        ├── presentation.pdf          # 발표 자료 PDF
        └── pic/                      # 발표용 사양·장비·노드 이미지
```

## 주요 문서

| 문서 | 내용 |
| --- | --- |
| [전체 보고서](report.md) | 시스템 구성부터 문제 1~5의 구현·측정·해석까지 |
| [발표 원고](presentation.md) · [발표 PDF](results/presentation/presentation.pdf) | 문제 정의, 인지·제어, 결과와 배운 점 |
| [팀 구성과 기여](team.md) | 팀원별 역할과 구현·협업 기록 |
| [인지 튜닝·평가](results/PERCEPTION.md) | 검출기 실행과 튜닝·평가 도구 안내 |
| [토픽·인터페이스](results/bringup/TOPICS.md) | 문제 2 관련 노드 연결, 메시지 규약, QoS 및 정지 규칙 |
| [파라미터 설명](results/bringup/parameter.md) | 추적·제어 설정의 의미 |
| [OpenCR 제어](results/control/opencr_control_report.md) | 하드웨어 제어 흐름 설명 |
| [Python 제어 코드 설명](results/control/main_control/main_py_report.md) | `main.py`의 구조와 동작 |

## 문제별 결과

| 문제 | 상세 자료 |
| --- | --- |
| 1 — 색 기반 검출 | [보고서](results/answer/problem1/report_problem1.md) 및 원본·마스크·오버레이 캡처 |
| 2 — 인터페이스 규약 | [전체 보고서](report.md)와 [토픽 문서](results/bringup/TOPICS.md) |
| 3 — 중심 기반 추적 제어 | [보고서](results/answer/problem3/report_problem3.md), Kp별 그래프와 GIF |
| 4 — 성능 측정과 소실 복구 | [보고서](results/answer/problem4/report_problem4.md), 평가 프레임과 시험 영상 |
| 5 — bag 재현과 팀 협업 | [보고서](results/answer/problem5/report_problem5.md), 재현 캡처와 실행 로그 |

`results/bags/`의 원본 기록과 `csv/`, `plots/`의 분석 결과를 함께 확인하면 보고서의 측정 근거를 추적할 수 있습니다. 전체 시스템 실행에 관한 명령과 환경 설명은 각 문서를 참고하세요.

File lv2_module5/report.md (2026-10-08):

# ROS-Vision-Tracker 통합 보고서 — 팀 Xmen

색으로 구분되는 목표를 RealSense D435로 검출하고, 화면 중심 오차를 팬·틸트 짐벌의 각속도 명령으로 바꿔 목표를 화면 중앙에 두는 시스템이다.

| 장 | 내용 |
| --- | --- |
| 0. 공통 | 장비·전체 흐름, 구동·펌웨어 |
| 1. 문제 1 | 색 기반 검출 — 구현·설정·HSV 근거·조명/거리 측정·해석·한계 |
| 2. 문제 2 | 인터페이스 규약·QoS·다섯 입력 확인·해석·한계 |
| 3. 문제 3 | P 제어·부호 결정·Kp 12회차 측정·영상·해석·한계 |
| 4. 문제 4 | 상태기계·정지 보장·필수 시험 4종·지표·해석·한계 |
| 5. 문제 5 | bag 기록·재현(입력 재처리 vs 결과 재분석)·다른 팀원 실행·해석·한계 |
| 6. 심화 | 발제 심화 항목 중 수행한 것 |

---

# 0. 공통 — 장비·구동

## 0.1 장비와 전체 흐름

| 구분 | 사양 |
| --- | --- |
| 컴퓨터 | Raspberry Pi (Ubuntu 26.04, ROS 2 Lyrical). 원격 PC는 RViz 시각화·분석 전용 |
| 카메라 | RealSense D435, 컬러 640×360@30, 컬러에 정렬한 뎁스(32FC1, m) |
| 구동 | OpenCR + Dynamixel XM430-W350 2대 — 팬 ID11, 틸트 ID12 |
| 목표 | 파란 30×30×60 mm 직육면체(블루 큐브) |

```bash
[D435] ─영상+뎁스─▶ 인지 ─/target(ex, ey, 면적비)─▶ 제어 ─/cmd_vel(rad/s)─▶ 구동(시리얼 브리지)
                     │                              │                            │ "v 팬 틸트"
                     └─/perception_status           └─/tracking_status           ▼
                                                                          [OpenCR 펌웨어] ─▶ Dynamixel
                                                                                │
                                                                  /joint_states ◀┘ (약 2 Hz)
```

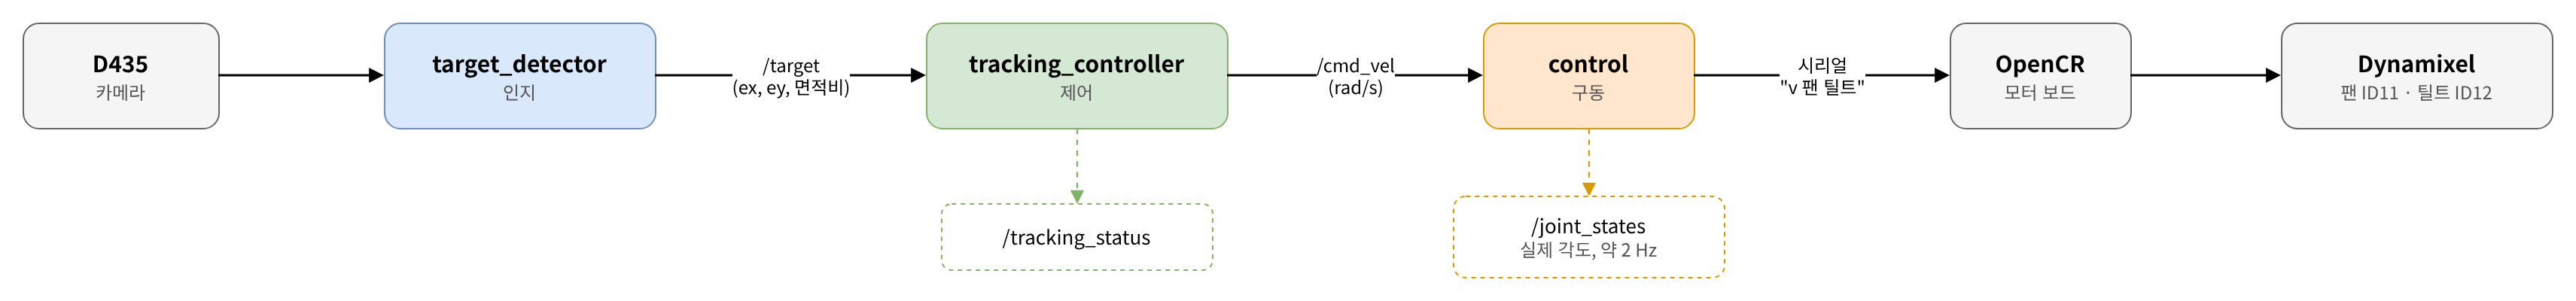
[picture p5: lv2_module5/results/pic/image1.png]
시스템 전체 흐름


| 단계 | 책임 | 다루는 장 |
| --- | --- | --- |
| 인지 | 목표를 찾고 **화면 중심 오차만** 낸다. 모터·제어를 모르고, 상태를 프레임 간에 저장하지 않는다 | 1장 |
| 연결 | 오차·상태를 정해진 토픽·QoS·시각 규약으로 주고받는다 | 2장 |
| 제어 | 오차 → 각속도 명령. 부호·이득·상한·데드밴드·타임아웃·상태 판정을 모두 여기서 정한다 | 3·4장 |
| 구동 | 명령을 그대로 시리얼로 중계한다. 부호를 바꾸지 않고, 실패하면 0을 보낸다 | 0.2절 |
| 펌웨어 | 범위·가속·워치독 등 **하드웨어 안전**을 책임진다. 상위가 죽어도 스스로 멈춘다 | 0.2·4.2절 |

OpenCR은 컴퓨터에서 받은 회전 명령으로 팬·틸트 모터를 움직이는 제어 보드다. 시리얼 통신으로 전달된 명령을 Dynamixel 모터에 적용하며, 회전 범위와 가속도를 제한한다. 일정 시간 동안 새 명령이 들어오지 않으면 워치독이 모터를 정지시켜 통신이 끊겼을 때도 안전하게 멈추도록 한다.

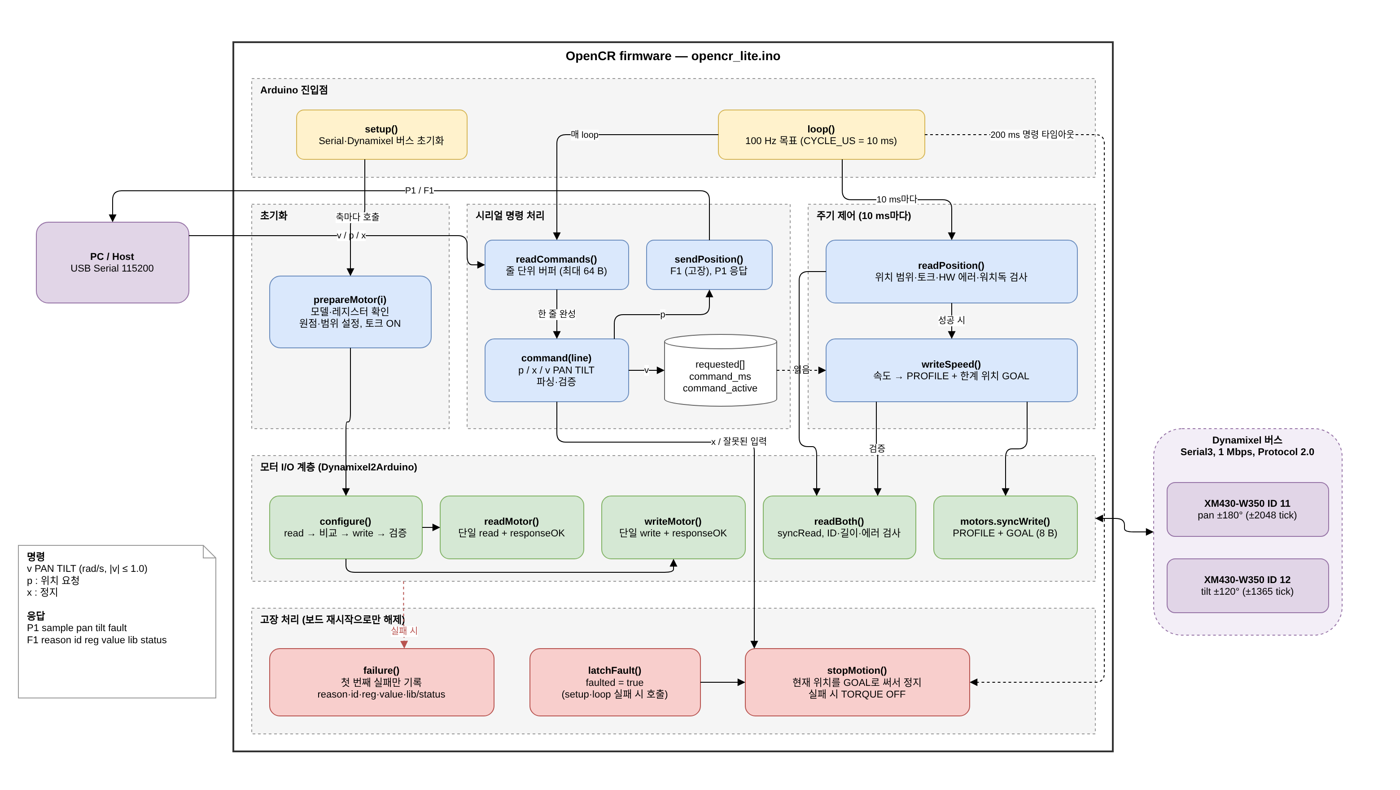
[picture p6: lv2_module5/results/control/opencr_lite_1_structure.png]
OpenCR 펌웨어 구조


*`opencr_lite.ino` 전체 구조 — 왼쪽 PC와 USB 시리얼(115200)로 명령(`v PAN TILT` / `p` / `x`)을 주고받고, 오른쪽 Dynamixel 버스(Serial3, 1 Mbps)로 pan ID11·tilt ID12를 움직인다. `setup()`이 축을 준비(`prepareMotor`)하고, `loop()`는 100 Hz로 시리얼 명령 처리와 주기 제어(`readPosition` → `writeSpeed`)를 돌린다. 아래 붉은 블록은 고장 처리로, 200 ms 동안 명령이 없거나 검사에 실패하면 `stopMotion()`으로 그 자리에 멈춘다*

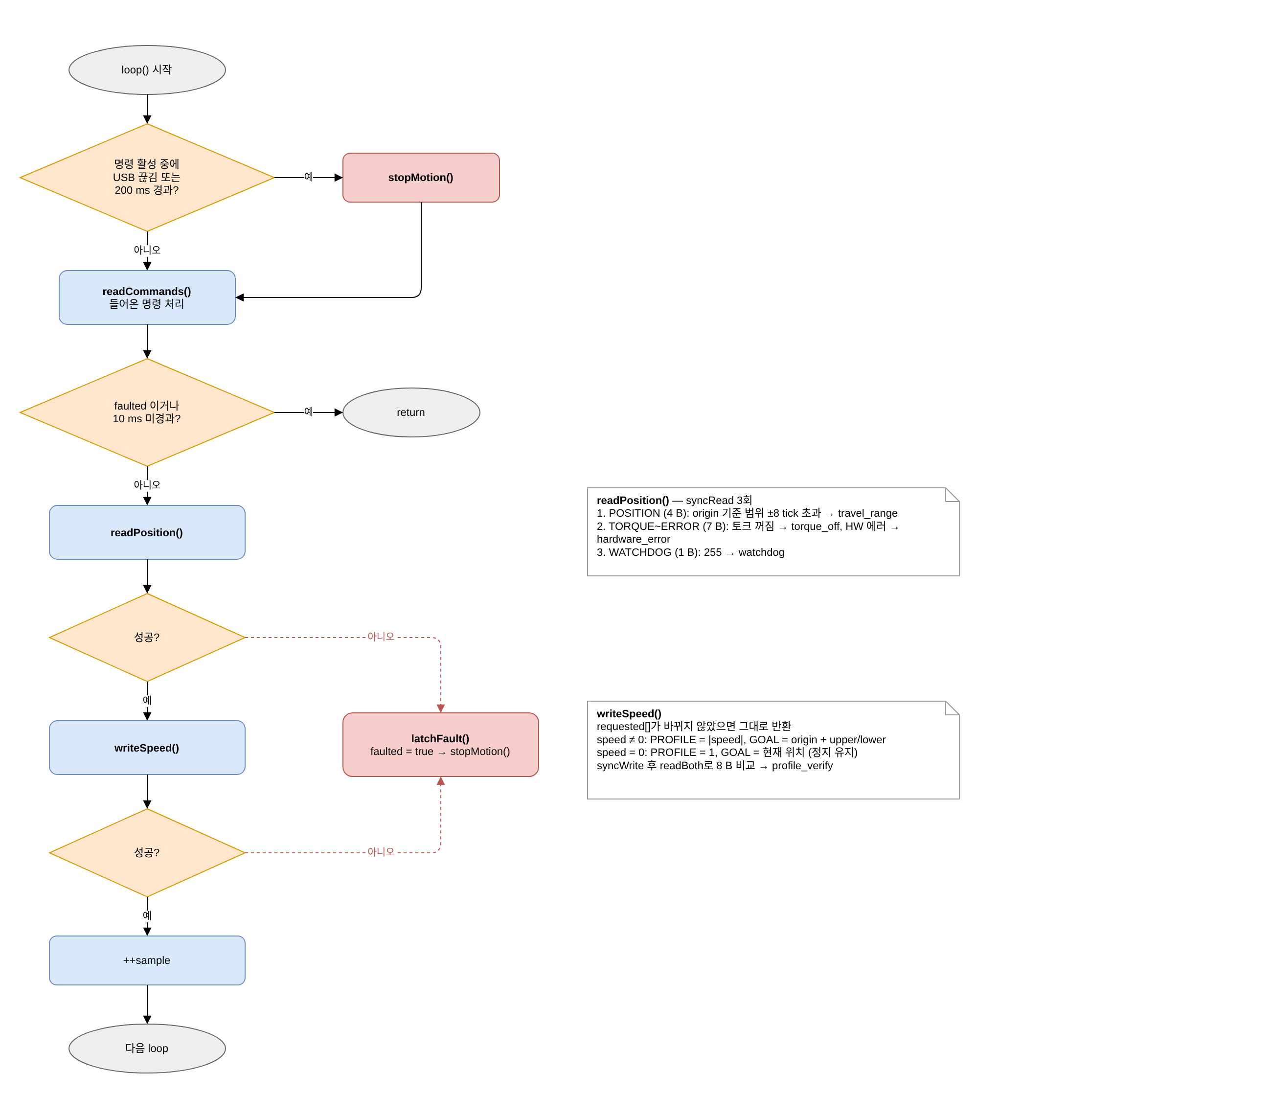
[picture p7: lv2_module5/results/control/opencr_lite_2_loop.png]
OpenCR 제어 루프


*`loop()` 한 주기의 흐름 — ① 명령이 활성인데 USB가 끊겼거나 200 ms가 지났으면 바로 `stopMotion()`(워치독), ② `readCommands()`로 들어온 줄을 처리, ③ FAULT 상태이거나 아직 10 ms가 안 됐으면 그대로 반환, ④ `readPosition()`으로 위치·토크·HW 에러·워치독을 검사하고 ⑤ `writeSpeed()`로 속도를 PROFILE + 한계 위치 GOAL로 바꿔 내보낸다. 두 검사 중 하나라도 실패하면 `latchFault()`로 고장을 걸고 정지한다*

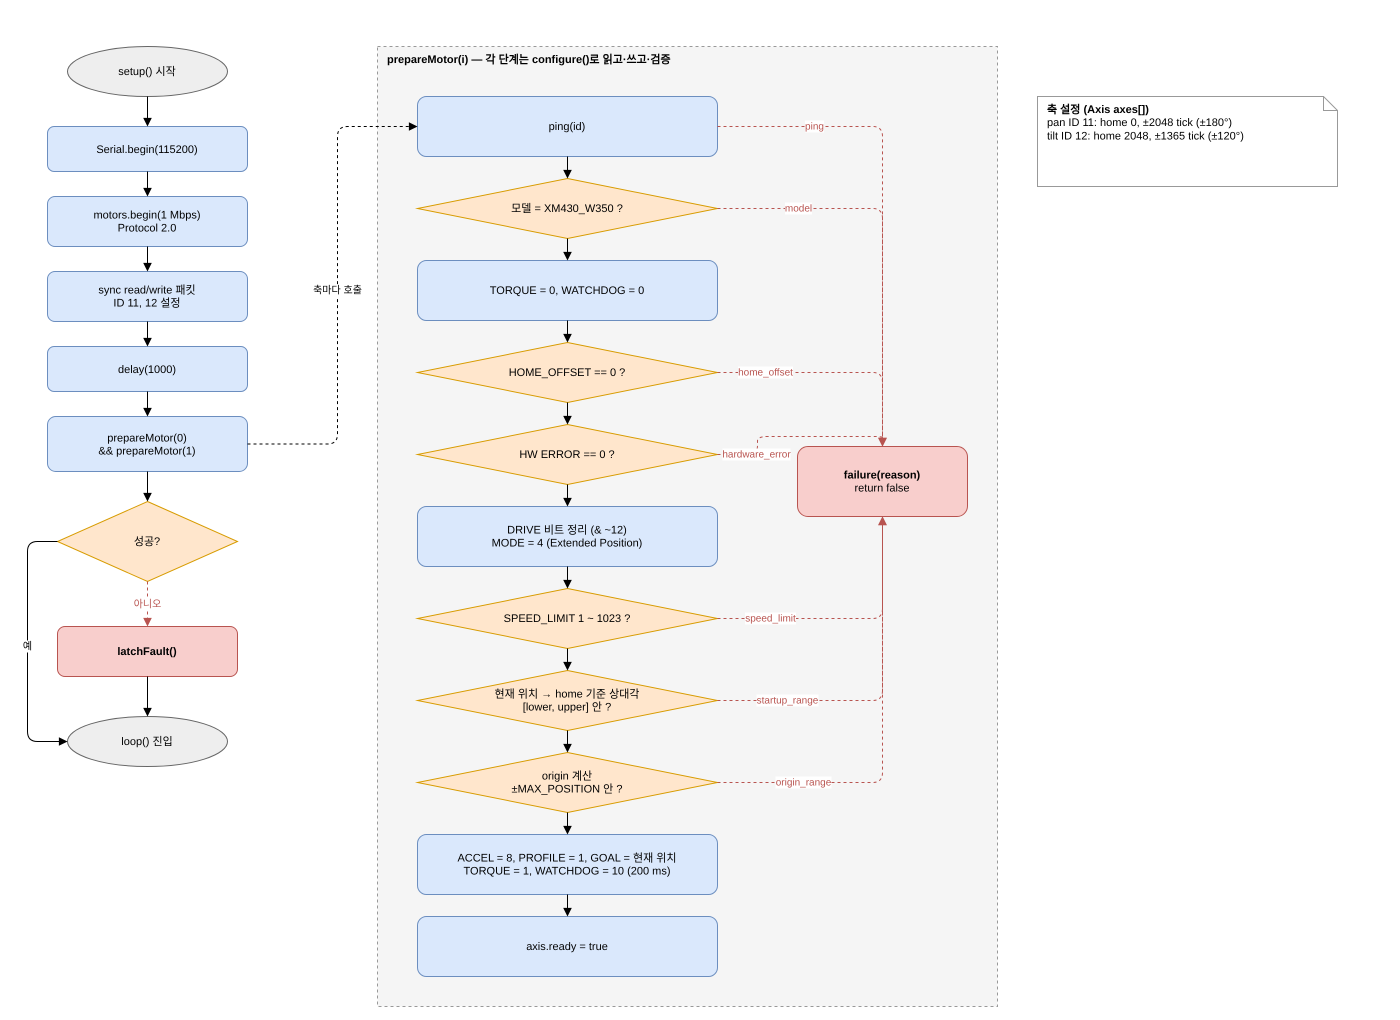
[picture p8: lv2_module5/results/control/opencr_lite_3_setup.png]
OpenCR 초기 설정


*`setup()`과 축 준비 절차 — 시리얼·Dynamixel 버스를 열고 두 축에 `prepareMotor()`를 부른다. 오른쪽 상자가 그 내용으로, ping → 모델 확인 → 토크·워치독 해제 → Homing Offset·HW 에러·속도 상한 검사 → 현재 위치가 허용 범위 안인지 확인 → 원점(origin) 계산 순서다. 모두 통과해야 토크를 켜고 워치독 200 ms를 걸며 `axis.ready = true`가 된다. 한 단계라도 실패하면 `failure(reason)`으로 이유를 남기고 `latchFault()` 상태로 `loop()`에 들어간다*

---

# 1. 문제 1 — HSV·Contour 검출 파이프라인

목표는 **파란 30×30×60 mm 직육면체(블루 큐브)** 다. 배경(흰 사물함·책상, 보라 의자, 청회색 카펫)과 색으로 구분된다.

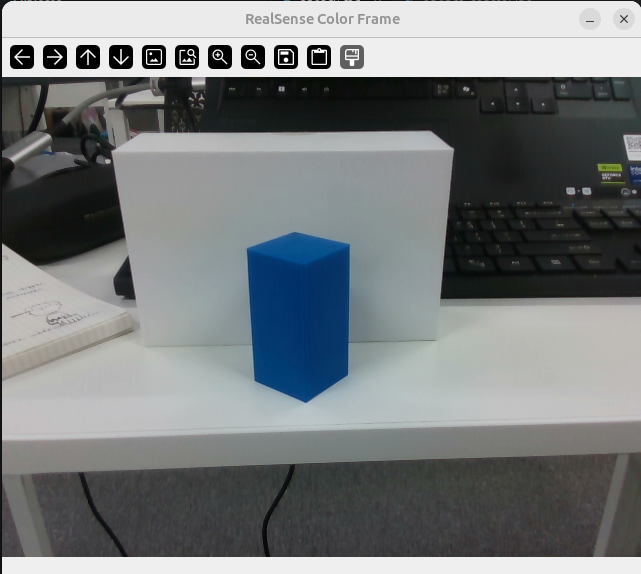
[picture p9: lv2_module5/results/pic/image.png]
파란 직육면체 목표


## 1.1 구현 내용

`영상 → 해상도 맞춤 → HSV 변환 → 색상 마스크 → 잡음 제거 → 컨투어 → 후보 판정 → 대상 선택 → 중심·오차`

| 단계 | 내용 |
| --- | --- |
| 해상도 맞춤 | 처리 해상도 640×360 고정. 비율이 다른 입력은 늘리지 않고 가운데를 16:9로 잘라 쓰고, 원본 좌표 복원 정보를 보관한다 |
| 색상 마스크 | 가우시안 블러(5) → BGR2HSV → `inRange(H 104 ~ 120, S 200 ~ 255, V 8 ~ 255)`. 색 세기(max−min) 5 미만 픽셀 제외 |
| 잡음 제거 | 5×5 타원 커널 열림 1회(점 잡음) → 닫힘 2회(구멍 메움) |
| 컨투어·후보 판정 | `RETR_EXTERNAL` 외곽 컨투어 → 면적 → 모양(장변/단변, 채움비, solidity) → 뎁스 거리·실제 크기 |
| 대상 선택 | 통과 후보 중 면적 최대. 면적 차가 10%(`tie_ratio`) 이내면 영상 중심에 더 가까운 것 |
| 중심 계산 | 볼록껍질(convex hull)의 모멘트 중심 `m10/m00, m01/m00`(`m00 = 0`이면 탈락) — 하이라이트·그늘에 덜 끌려간다 |

정규화 오차:

**ex = (cx − W/2)/(W/2), ey = (cy − H/2)/(H/2)** (오른쪽·아래쪽 양수),

면적비: 

**contour_area/(W×H)**

- W·H는 실제 프레임 크기
- 처리 좌표:  `to_original()`원본 프레임 좌표로 되돌린 뒤 오차를 계산한다.

표시: 

- 초록 굵은 선 = 선택된 목표
- 노랑/회색 = 통과했지만 미선택/탈락 후보
- 빨간 점 = 목표 중심(중심까지 빨간 선)
- 흰 십자 = 영상 중심
    - 윗줄 = `DETECTED c=(원본 좌표) ex ey area n` 또는 `NO TARGET center=None ex=None ey=None`
    - 둘째 줄 = 뎁스 `Z=…m size=…cm`.
    - 

**미검출 시 이전 좌표를 재사용하지 않는다.** 

`detect()`는 프레임 간 상태를 전혀 갖지 않고, 통과 후보가 없으면 `detected=False`와 함께
중심·오차·면적비·bbox를 모두 `None`으로 반환한다. 

기록 JSON에는 `null`, 화면에는 `NO TARGET`으로 남고 목표 중심을 그리지 않는다.

세 장면(잘 보임 · 없음 · 일부 가림)은 **같은 설정 파일**로 처리했고, 원본·마스크·검출 이미지 9장을 `problem1/capture/`에 남겼다.

가림 장면은 보이는 부분(1.5 × 2.7 cm)만으로 검출했고, 마스크의 작은 점은 `too_small`로 탈락했다.

## 1.2 설정 — 측정에 쓴 값 (`detector.yaml`)

발제 요구대로 HSV 범위·최소 면적·해상도를 코드에서 분리했다. 코드 수정 없이 이 파일만 바꿔 튜닝한다.

| 구분 | 키 | 값 |
| --- | --- | --- |
| HSV 범위 | `target.hsv_ranges` | lower `[104, 200, 8]`, upper `[120, 255, 255]` (빨강처럼 0/179를 넘는 색은 범위를 2개 적어 합집합) |
| 색 세기 하한 | `target.min_chroma` | 5 |
| 목표 크기·거리 | `target.size_mm`, `distance_range_m` | 30×30×60 mm, 0.1 ~ 1.0 m |
| 해상도 | `processing.width/height` | 640 × 360 |
| 잡음 제거 | `blur_ksize`/`morph_kernel`/`open`/`close` | 5 / 5 / 1회 / 2회 |
| 최소 면적 | `selection.min_area` | auto = 0.3 × (1 m에서 30×30 면의 화면 넓이) → fx 454.1에서 55 px (뎁스 없을 때) |
| 최대 면적 | `selection.max_area_ratio` | auto → 0.6 (화면의 60% 초과는 배경) |
| 모양 | `max_aspect`/`min_extent`/`min_solidity` | 3.0 / 0.35 / 0.5 |
| 선택 규칙 | `tie_ratio`, `center_method` | 0.1, `hull` |
| 뎁스 | `depth.min_m`/`max_m` | 0.1 ~ 1.1 m |
| 뎁스 | `depth.min_area_px` / `no_depth_min_area` | 80 px / 800 px(뎁스 측정 실패 시 색만으로 믿을 최소 면적) |
| 실제 크기 | `max_short_m`/`max_long_m`/`area_m2` | 짧은 변 ≤ 5 cm, 긴 변 ≤ 8 cm, 3 ~ 30 cm² |
| 뎁스 분할 | `split`, `split_jump_m` | true, 0.02 m (앞뒤로 겹친 같은 색 덩어리 분리) |
| 카메라 | `exposure` / `white_balance` / `options` | 노출 자동, 화이트밸런스 4600 K 고정, `auto_exposure_priority: 1` |

조명이 바뀌는 환경이라 **노출은 자동**(밝기 변화를 카메라가 흡수), **화이트밸런스는 고정**(색상 H가 흔들리지 않게)으로 두었다.

### 1.2.1 실험 이후 바뀐 검출 설정

HSV 범위·해상도·거리 조건은 그대로이고, **모양 판정과 가림 처리가 강화**됐다. 1.5절 수치는 아래 변경 **이전** 설정으로 측정한 것이다.

| 항목 | 실험 당시 | 현재 | 바꾼 이유(설정 파일 주석) |
| --- | --- | --- | --- |
| `min_extent` | 0.35 | **0.60** | 홈·구멍이 있는 같은 색 물체(파란 3D 프린트 브래킷, extent 0.52 ~ 0.53) 제외. 실측 큐브는 0.84 ~ 0.99 |
| `min_solidity` | 0.5 | **0.75** | 같은 이유(브래킷 0.67 ~ 0.68, 큐브는 반쯤 가려도 0.98) |
| `box_fit` | 없음 | **추가** | 실루엣을 꼭짓점 ≤ 6 다각형으로 근사해 평균 틈을 본다 → 원·타원·고리 제외. 500 px 미만은 해상도 부족으로 검사 생략 |
| `partial` | 없음 | **추가** | 화면 가장자리에 잘렸거나(`border`), 뎁스로 본 앞 물체에 가려진(`occluded`) 경우에만 모양·넓이 하한을 완화. 홈이 있는 다른 물체는 오목부 뒤가 더 멀어 완화되지 않는다 |
| `depth.min_area_px` | 80 | **60** | 1 m에서 일부만 보이는 큐브를 놓쳤다(모의 1293 → 1323/1430) |
| `depth.max_short_m` | 0.05 | **0.06** | 모서리가 카메라를 향한 자세(짧은 변 5.0 ~ 5.3 cm)를 놓쳤다 |

즉 **배경 오검출을 더 줄이면서(모양 강화) 가림·잘림에는 더 관대해지는(`partial`) 방향**이다.
4.5절의 역광 미검출 5장은 이 변경으로 해결되지 않는다 — 원인이 모양이 아니라 노출이기 때문이다.

## 1.3 HSV 범위를 정한 근거

조명 3종 × 거리 0.15 ~ 1.0 m, 1,400장을 측정해 정했다.

|  | 큐브 (p2 ~ p98) | 배경 중 H 100 ~ 125 픽셀 |
| --- | --- | --- |
| H | 110 ~ 113 | 넓게 분포(배경 전체 중앙값 122 ~ 128) |
| S | 248 ~ 255 | 중앙값 69 ~ 83, 상위 1% 124 ~ 163 |
| V | 38 ~ 46(어두움), 84 ~ 103(보통·밝음) | 중앙값 120 ~ 138 |
- S 하한을 바꿔 가며 전체 데이터로 평가하면 **170 ~ 230에서만 인식 100%·오검출 0%** → 가운데 200.
- H는 96 ~ 130 어디서나 통과 → 큐브 H 112를 가운데로 104 ~ 120.
- V 하한은 8 ~ 38 모두 통과 → 더 어두운 환경을 위해 8(더 낮은 밝기는 색 세기 하한 5로 거른다).
- 처음 범위 `[103,208,26] ~ [116,…]`은 큐브 앞면 8×12 px만 보고 정한 값이었다.

## 1.4 배경 오검출을 줄인 조건 · 미검출 전달 방식

| 조건 | 효과(근거) |
| --- | --- |
| 채도 하한 S ≥ 200 | 배경의 옅은 파랑(의자·카펫·데님) 제외. 배경 파란 계열의 99%가 S < 163 |
| 완화 범위(relaxed) 제거 | "진한 파랑과 붙은 S ≥ 80 픽셀"을 인정하면 의자·카펫(S 80 ~ 125)이 큐브에 붙어 덩어리가 커졌다. 제거 후 큐브 없는 장면 오검출 **75% → 0%** |
| 색 세기 하한 5 | 어두운 픽셀은 잡음만으로 S가 커진다 |
| 모양 조건 | 줄무늬·막대·구불구불한 덩어리 제외(뎁스 유무와 무관하게 항상 적용) |
| 뎁스 거리·실제 크기 | 뒤쪽 멀리 있는 같은 색 물체, 같은 색이지만 크기가 다른 물체(카드·셔츠) 제외 |

| 위치 | 미검출 표현 |
| --- | --- |
| `detect()` 반환 | `detected=False`, 중심·오차·면적비·bbox = `None` |
| 기록 JSON | 위 값이 `null` |
| 화면 | `NO TARGET center=None ex=None ey=None`, 목표 중심을 그리지 않음 |
| `/target` | `point.z = 0` (x·y = 0)으로 **매 영상마다 발행**. 받는 쪽은 z = 0이면 x·y로 제어하지 않는다 |
| 카메라 정지 | 0.3 s 새 영상 없음 → 발행하지 않고 `/perception_status = CAMERA_STALL` |

## 1.5 측정 결과 — 조명·거리별 검출률·처리 속도 (심화)

같은 데이터(조건당 100장)를 최종 설정과 최적화 전 설정으로 처리했다.
처리 시간은 해상도 맞춤 ~ 중심 계산(색·모양·뎁스 검증 포함)이고 화면 표시·카메라 대기는 뺐다.

조명 변화 (거리 약 0.5 m 고정)

| 조명 | 최종 검출률 | 최종 처리 ms (평균/p95) | 최적화 전 검출률 | 최적화 전 처리 ms |
| --- | --- | --- | --- | --- |
| 어두움 | 100% | 1.03 / 1.26 | 0% | 7.58 / 9.36 |
| 보통 | 100% | 0.96 / 1.15 | 100% | 6.07 / 6.62 |
| 밝음 | 100% | 0.97 / 1.12 | 100% | 2.84 / 3.03 |

거리 변화 (보통 조명, 1.0 m는 어두움·밝음)

| 거리(실측 Z) | 최종 검출률 | 최종 처리 ms | 최적화 전 검출률 | 최적화 전 처리 ms |
| --- | --- | --- | --- | --- |
| 0.1 m (0.16 m) | 100% | 1.03 / 1.18 | 100% | 3.19 / 3.36 |
| 0.2 m (0.32 m) | 100% | 1.03 / 1.17 | 100% | 6.05 / 6.52 |
| 0.5 m (0.55 m) | 100% | 0.96 / 1.15 | 100% | 6.07 / 6.62 |
| 1.0 m 어두움 (1.02 m) | 100% | 1.28 / 1.46 | 0% | 7.04 / 8.82 |
| 1.0 m 밝음 (1.02 m) | 100% | 0.96 / 1.11 | 3% | 5.42 / 5.90 |
- 평균 처리 5.3 ms → **1.0 ms**.
- 뎁스는 0.15 ~ 1.03 m 전 구간에서 99 ~ 100% 측정됐고, 실측 크기는 2.0 ~ 3.1 × 5.4 ~ 6.2 cm였다.
- 실시간 처리의 한계는 검출이 아니라 카메라다: 프레임 대기 26.4 ms(≈30 fps) 대 검출 1 ms.

## 1.6 해석

1. **배경 분리는 채도(S)가 결정한다.** 큐브 S는 248 ~ 255인데 배경의 파란 계열은 99%가 S < 163이라, S 하한 하나로 의자·카펫·데님을 거의 다 걷어냈다. 색상(H)·명도(V)는 넓게 둬도 성능이 변하지 않았다.
2. **"놓치지 않으려고" 범위를 넓히면 오히려 더 놓친다.** 진한 파랑에 붙은 옅은 파랑까지 인정하는 완화 범위를 두었더니, 어두운 장면에서 의자·카펫이 큐브에 붙어 실제 크기가 12 ~ 77 cm로 계산돼 크기 불일치로 탈락했다(어두움 검출률 0%). 완화 범위를 **제거**하자 100%가 됐다. 검출률을 올린 것은 느슨함이 아니라 엄격함이었다.
3. **처리 시간도 같은 이유로 줄었다.** 덩어리가 커지면 뎁스 분할까지 시도해 최대 9.4 ms가 걸렸지만, 마스크가 큐브만 남은 뒤로는 조건과 무관하게 약 1 ms로 일정하다. 병목은 검출이 아니라 카메라(26.4 ms/프레임)다.
4. **남은 실패는 역광이다.** 4.5절에서 놓친 5장이 모두 조명·창을 배경으로 한 역광 구간에 몰려 있다. 자동 노출이 밝은 배경에 맞춰지면 큐브가 어두워져 S·V가 함께 떨어진다. HSV 범위를 넓혀서가 아니라 노출·역광 보정 쪽에서 풀어야 한다.

---

# 2. 문제 2 — 인지·제어 노드 연결

## 2.1 구현 내용 — 인터페이스 규약

| 항목 | 구현 |
| --- | --- |
| 목표 토픽 | `/target` · `geometry_msgs/msg/PointStamped` |
| `point.x` / `point.y` | ex / ey (오른쪽·아래쪽 양수, [−1, 1]) |
| `point.z` | 면적비. **0 = 미검출** — 이때 x·y로 제어하지 않는다 |
| `header.stamp` | 원본 영상 **촬영 시각**(RealSense global time). 촬영 시각을 얻지 못하면 수신 시각을 쓰고 그 사실을 detector 로그에 남긴다 |
| `header.frame_id` | `camera_color_optical_frame` |
| 발행 | 영상 처리마다(약 30 Hz). 정상 영상의 미검출은 **z = 0으로 발행** |
| QoS | `/target` best-effort · keep_last 1. 상태·명령은 reliable · keep_last 1 |
| 상태 토픽 | `/perception_status` (OK · NO_TARGET · CAMERA_STALL), `/tracking_status` (WAITING · TRACKING · CENTERED · LOST · TIMEOUT · IDLE) |
| 모터 명령 | **속도 방식**. `/cmd_vel` `angular.z` = 팬, `angular.y` = 틸트, 단위 rad/s, 20 Hz 고정. 정지 = 두 축 0.0을 **계속 발행**(발행 중단이 아니다) |
| 타임아웃 | 발제 기본값 0.5 s 그대로. 변경하지 않았다 |

**미검출과 통신 중단을 구분한다.** 목표가 없을 뿐이면 z = 0을 계속 발행하고, 새 영상이 0.3 s 없으면 `/target` 발행을 멈추고 `CAMERA_STALL`을 낸다.
받는 쪽은 "z = 0"과 "토픽 침묵"을 다르게 처리한다(전자는 LOST, 후자는 0.5 s 뒤 TIMEOUT).

**이전 영상에 새 시각을 붙여 보내지 않는다.** 인지는 `header.stamp`(또는 프레임 번호)가 이전 이하이면 그 영상을 버리고 발행하지 않으며,
제어는 같은·이전 stamp(`old_or_duplicate_stamp`), 촬영 시각이 0.5 s보다 오래된 입력(`too_old`), NaN·범위 밖 값(`invalid`)을 각각 분류해 거부한다.

**노드별 책임**은 0.1절 표와 같다 — 인지는 오차만, 제어는 부호·이득·상태 판정, 구동은 중계, 펌웨어는 하드웨어 안전이다.

## 2.2 설정 — 토픽·QoS

| 토픽 | 타입 | QoS | 주기 |
| --- | --- | --- | --- |
| `/target` | `PointStamped` | best-effort, keep_last 1 | 영상마다(약 30 Hz) |
| `/perception_status` | `String` | reliable, keep_last 1 | 상태 변화 시 + 1 Hz |
| `/cmd_vel` | `Twist` | reliable, keep_last 1 | 20 Hz 고정 |
| `/tracking_status` | `String` | reliable, keep_last 1 | 20 Hz |
| `/joint_states` | `JointState` | reliable, keep_last 1 | 약 2 Hz(`p` 폴링 응답) |
| 영상(`image_raw` 쌍) | `Image` | reliable, keep_last 5 | 30 Hz |

최신 값만 의미 있는 `/target`은 best-effort(늦은 재전송보다 다음 프레임이 낫다), 유실되면 안 되는 상태·명령은 reliable이다.
큰 영상은 best-effort로 받으면 조각 유실로 대부분 버려져(PC 실측 163장 중 7장만 수신) reliable·depth 5를 쓴다.
**구독 측 호환:** `/target`을 reliable로 구독하면 아무것도 받지 못한다 — 확인은 `ros2 topic echo /target --qos-reliability best_effort`.

## 2.3 측정 결과 — 다섯 입력 확인

발제가 요구한 "모터 출력 OFF + 다섯 입력" 확인은 **전용 로그를 제출하지 못했다.**

| 입력 | 기대 결과 | 현재 상태 |
| --- | --- | --- |
| x = 0, z > 0 | 중심에서 불필요한 회전 없음 | 데드밴드 0.05로 구현. 전용 로그 없음 |
| x = +0.4, z > 0 | 오른쪽 오차를 줄이는 명령 | 추적 기록으로 간접 확인(아래). 모의 입력 전용 로그 없음 |
| x = −0.4, z > 0 | 반대 방향 명령 | 동일 |
| z = 0 | 이전 목표를 계속 쫓지 않고 정지 | 4.4절 가림 시험 5회로 간접 확인(≤ 0.05 s 정지) |
| 발행 중단 | 타임아웃 감지 후 정지 | 4.4절 인지 입력 중단 시험으로 확인(0.541 s) |

**부호 반응은 실제 추적 기록으로 확인했다.** 문제 4의 4개 bag에서 검출·TRACKING·CENTERED 프레임만 보면
ex > +0.06인 1,169프레임 중 **1,159(99.1%)**에서 팬 명령이 음수(오른쪽), ex < −0.06인 1,098프레임 중 **1,087(99.0%)**에서 양수였다.
**반대 부호 명령은 이 4개 bag에서 한 번도 없었고**, 어긋난 프레임 21개는 모두 명령이 0인 경우(복귀 직후·데드밴드 경계)였다.
(프레임별 CSV는 문제 4의 4개 bag에만 있어 Kp 12회차는 이 집계에 넣지 않았다.)
다만 이것은 실제 추적 중 기록이지 발제가 요구한 "모터 출력 OFF + 지정 입력값" 시험은 아니다.

실험 당시 구성에는 `/target`을 모의 발행해 11단계를 PASS/FAIL·CSV로 검사하는 노드(`input_test`)와, 명령을 적분한 가상 짐벌로 부호를 보는 `gimbal_sim`,
토픽 타입·QoS·주기 호환성을 검사하는 `interface_check`가 있었으나 **출력 CSV가 저장소에 없고 리팩터링 후 코드도 남아 있지 않다.**
다섯 입력 시험은 `hardware_launch.py start_control:=false`(모터 출력 OFF)로 재수행해 로그를 남겨야 한다(7.2절).

## 2.4 해석

1. **부호가 반대이면 "조금 느린 추적"이 아니라 발산한다.** 첫 시험(`cmd_sign_tilt = +1`)에서 목표가 화면 아래(ey ≈ +0.9)에 있을 때 틸트 명령이 +0.4(위)로 나가 목표가 화면 밖으로 밀렸고, LOST↔TRACKING이 반복됐다. `−1`로 바꾼 뒤 해소됐다. 모터가 반대로 돈다고 Kp부터 올리면 안 되는 이유가 이것이다.
2. **부호 지점은 한 곳이어야 한다.** 시험 중 구동 쪽에 틸트 반전이 임시로 들어가 부호가 두 번 뒤집힌 적이 있다. 반전을 제거하고 제어기 한 곳에서만 정하도록 되돌렸다.
3. **미검출과 토픽 침묵을 나눈 덕에 대응이 달라졌다.** z = 0은 그 프레임에서 바로 LOST·정지로, 토픽 침묵은 0.5 s 뒤 TIMEOUT으로 간다. 실제로 인지 프로세스를 죽였을 때 0.541 s에 정지했고(4.4절), 가림 때는 0.05 s 안에 정지했다 — 같은 "정지"지만 경로와 지연이 다르다.
4. **QoS는 토픽 성격에 맞춰야 한다.** 영상을 best-effort로 받았을 때 163장 중 7장만 남은 실측이 있어 영상만 reliable·depth 5로 바꿨다. 반대로 `/target`을 reliable로 구독하면 아무것도 받지 못한다.

---

# 3. 문제 3 — 객체 중심 기반 추적 제어

## 3.1 구현 내용 — 제어식과 부호 결정

속도형 P 제어, 축마다 독립이다.

```
command = 0                                                      (|e| < deadband)
command = clamp(direction × Kp × e, -speed_limit, +speed_limit)   (그 외)
```

- **단위:** Kp는 [rad/s] per 정규화 오차 1.0, 명령은 rad/s. ex = 1은 화각 절반(팬 약 35°, 틸트 약 21°)에 해당한다.
- **적분 없음:** 각속도 명령을 그대로 보내므로 제어기에서 dt로 적분하지 않는다. 위치 변화는 펌웨어·모터 프로파일이 만든다.
- **주기:** 20 Hz 타이머가 입력 주기와 무관하게 상태 판정·명령 계산·발행을 한다.
- **제한:** 속도 상한 0.6 / 0.4 rad/s, 데드밴드 0.05(≈1.8°), 회전 범위는 펌웨어가 팬 ±180°·틸트 ±135°로 지키고 범위 끝에서 감속 후 위치를 유지한다.

**부호 결정 절차(발제 1·2번).** 추적을 끄고 구동만 켠 상태에서 축마다 작은 명령(0.1 rad/s)을 보내 실제 회전 방향을 먼저 확인했다.

```bash
ros2 topic pub -r 20 /cmd_vel geometry_msgs/msg/Twist "{angular: {z: 0.1}}"   # 팬
ros2 topic pub -r 20 /cmd_vel geometry_msgs/msg/Twist "{angular: {y: 0.1}}"   # 틸트
```

| 축 | `+` 명령 시 실제 방향 | 오차 정의 | 결정한 direction |
| --- | --- | --- | --- |
| 팬 (`angular.z`) | 왼쪽 | ex > 0 = 목표가 오른쪽 → 오른쪽(음수)으로 회전 | `cmd_sign = -1` |
| 틸트 (`angular.y`) | 위 | ey > 0 = 목표가 아래 → 아래(음수)로 회전 | `cmd_sign_tilt = -1` |

판단 기준은 "목표를 오른쪽·아래에 두었을 때 카메라가 그쪽으로 돌아 **오차가 줄어드는지**"였다.
부호는 제어기 한 곳(`cmd_sign`·`cmd_sign_tilt`)에서만 정하고 구동은 변환 없이 그대로 전달한다(2.4절 해석 1·2).

## 3.2 설정 — 추적 파라미터

측정에 쓴 값(`tracking.yaml`)과 현재 저장소 값(`xmen_bringup/param/tracker.yaml`, 전체 설명은 parameter.md)이다.

| 항목 | 실험 당시 팬 / 틸트 | 현재 팬 / 틸트 | 비고 |
| --- | --- | --- | --- |
| Kp | **1.5 / 2.0 / 2.5 / 4.5**(비교 대상) / 0.8 | 1.5 / **1.2** | [rad/s] per 정규화 오차 1.0 |
| `direction`(`cmd_sign`) | −1 / −1 | −1 / **+1** | 3.1절 절차로 결정한 값은 둘 다 −1 |
| `speed_limit` | 0.6 / 0.4 | **0.9 / 0.6** | rad/s. 포화를 줄이려고 올렸다(3.6절 해석 반영) |
| `deadband` | 0.05 / 0.05 | 0.05 / 0.05 | 정규화 오차. 경계 ≈ 1.8° |
| `rate_hz` | 20 | 20 | 명령·상태 발행 주기 |
| `tracking_hz` | — (영상마다 검출, 약 30 Hz) | **20** | 가장 최근 RGB·뎁스 쌍만 20 Hz로 검출 |
| `timeout` / `max_input_age` | 0.5 / 0.5 | 0.5 / 0.5 | [s] 발제 기본값 |
| `recover_frames` | 3 | **없음** | 현재 코드에 상태기계가 없다(0.4절) |
| 회전 범위 | 팬 ±180° / 틸트 ±135° | 팬 ±180° / 틸트 **±120°** | 실험은 V3 펌웨어, 현재는 `opencr_lite.ino` |

> 남은 불일치는 **`cmd_sign_tilt: 1.0` 하나**다. 실험에서 −1로 확정했고 +1이면 틸트가 반대로 간다(2.4절 해석 1). `kp`·HSV 불일치는 해소됐다.
`speed_limit`을 0.9/0.6으로 올린 뒤의 재시험은 아직 하지 않았다 — 아래 수치는 모두 0.6/0.4 기준이다.
> 

## 3.3 시험 방법

- **시나리오:** 왼쪽 3 s 정지 → 중앙 3 s → 오른쪽 3 s → 중앙 3 s. 바닥에 위치 표시를 붙여 반복 조건을 맞췄다.
- 회차 시작 전 원점 복귀: `ros2 topic pub --once /opencr/home std_msgs/msg/Empty '{}'`
- **Kp 4종 × 3회 = 12회**(발제 최소 조건은 2종 × 3회). 보드 `tracking.yaml`에서 kp만 바꿔 bringup을 재시작했고 나머지는 고정했다.
- 회차마다 rosbag 기록: `/target /cmd_vel /tracking_status /joint_states /perception_status`
- 분석(PC): bag 재생 → `track_logger`로 CSV 변환 → `track_plot`으로 요약·그래프.
- 실제 Kp는 CSV의 명령/오차 비로 역산해 12회 모두 설정값과 일치함을 확인했다.
- 수평 RMSE = `sqrt(mean(ex²))`, 검출되고 상태가 TRACKING·CENTERED인 프레임만 사용(CENTERED는 데드밴드 안이라 명령이 0인 추적 상태). 사용·제외 프레임 수를 함께 적는다.
- 포화 비율 = 데드밴드 밖(|ex| > 0.06)에서 |명령| ≥ 0.59 rad/s(상한 0.6)인 비율.
- **흔들림 지표 2종** — 부호 반전 = 검출 프레임의 ex가 데드밴드(±0.05) **밖**에서 부호를 바꾼 횟수 / 10 s(0.05 이내 프레임은 건너뛴다. 팬 명령의 부호 반전 횟수와 12회 모두 같았다).
중심 근처 RMS = |ex| < 0.3 프레임만의 `sqrt(mean(ex²))` — 이동 직후 포화 구간을 뺀 값이다.

## 3.4 측정 결과 — Kp 12회차

| 회차 | 길이 [s] | 처리 FPS | 검출 출력 비율 | 사용/제외 | RMSE ex | RMSE ey | 최대 \|ex\| | 포화 비율 |
| --- | --- | --- | --- | --- | --- | --- | --- | --- |
| kp1.5_run1 | 35.4 | 29.9 | 0.882 | 907 / 152 | 0.202 | 0.097 | 0.966 | 0.03 |
| kp1.5_run2 | 19.6 | 29.6 | 1.000 | 581 / 0 | 0.264 | 0.077 | 0.522 | 0.32 |
| kp1.5_run3 | 18.5 | 30.0 | 0.998 | 552 / 2 | 0.317 | 0.079 | 0.623 | 0.37 |
| kp2.0_run1 | 31.3 | 30.0 | 0.989 | 927 / 13 | 0.172 | 0.088 | 0.540 | 0.10 |
| kp2.0_run2 | 18.2 | 30.0 | 0.768 | 412 / 135 | 0.395 | 0.085 | 0.842 | 0.62 |
| kp2.0_run3 | 20.5 | 30.0 | 0.998 | 611 / 4 | 0.295 | 0.076 | 0.948 | 0.41 |
| kp2.5_run1 | 42.1 | 30.0 | 1.000 | 1261 / 1 | 0.116 | 0.101 | 0.326 | 0.09 |
| kp2.5_run2 | 21.3 | 30.0 | 1.000 | 639 / 0 | 0.332 | 0.068 | 0.882 | 0.51 |
| kp2.5_run3 | 18.1 | 30.0 | 1.000 | 541 / 1 | 0.353 | 0.075 | 0.785 | 0.69 |
| kp4.5_run1 | 42.5 | 30.0 | 0.471 | 590 / 684 | 0.124 | 0.149 | 0.475 | 0.44 |
| kp4.5_run2 | 21.3 | 30.0 | 1.000 | 639 / 0 | 0.280 | 0.058 | 0.861 | 0.67 |
| kp4.5_run3 | 23.9 | 30.0 | 1.000 | 715 / 2 | 0.350 | 0.056 | 0.913 | 0.75 |

검출 출력 비율은 `/target`의 z > 0 비율이고(목표가 항상 화면 안에 있다는 가정), 사람이 영상과 대조한 4.5절 검출률과는 다르다.
처리 FPS는 `/target` 수 / 경과 시간이며 카메라 설정은 30 fps다.

**달라진 조건 기록(발제 요구):** run1은 **다른 세션에서 먼저** 기록했다(bag 녹화 시각 kp4.5 18:19, kp2.5 18:28, kp1.5 19:20, kp2.0 19:26 — run2·3은 모두 19:39 ~ 19:46).
기록 길이도 31 ~ 42 s로 run2·3(18 ~ 24 s)보다 길고 포화 비율이 3 ~ 10%로 낮다. 퍽을 더 천천히 옮기는 등 조건이 달랐던 것으로 보인다.
발제의 "Kp별 3회"는 run1을 포함해야 채워지므로 **3회 값을 참고 열로 함께 적고**, 조건을 맞춘 비교는 **run2·3**으로 한다.

| Kp | run2·3 RMSE ex (각 회차) | run2·3 평균 | 검출 출력 비율 | 포화 비율 | 참고: run1 포함 3회 평균 ± 표준편차 |
| --- | --- | --- | --- | --- | --- |
| 1.5 | 0.264, 0.317 | **0.291** | 0.999 | 0.35 | 0.261 ± 0.058 |
| 2.0 | 0.395, 0.295 | 0.345 | 0.883 | 0.51 | 0.288 ± 0.112 |
| 2.5 | 0.332, 0.353 | 0.342 | 1.000 | 0.60 | 0.267 ± 0.131 |
| 4.5 | 0.280, 0.350 | 0.315 | 1.000 | 0.71 | 0.252 ± 0.116 |

### 흔들림(진동) 비교

RMSE만으로는 Kp가 구분되지 않아, 같은 CSV에서 흔들림을 따로 계산했다.

| Kp | 부호 반전 / 10 s (run1, run2, run3) | 3회 평균 | run2·3 평균 | 중심 근처 RMS (run1, run2, run3) |
| --- | --- | --- | --- | --- |
| 1.5 | 2.3, 3.6, 2.7 | 2.9 | 3.1 | 0.161, 0.132, 0.146 |
| 2.0 | 1.9, 2.4, 2.4 | 2.3 | 2.4 | 0.142, 0.111, 0.132 |
| 2.5 | 1.9, 3.3, 2.8 | 2.7 | 3.0 | 0.113, 0.125, 0.110 |
| 4.5 | 4.3, 7.0, 6.7 | 6.0 | **6.9** | 0.096, 0.128, 0.118 |

시나리오상 목표가 중심을 지나는 이동이 있어 Kp와 무관하게 일정 횟수의 반전은 생긴다. Kp 간 비교는 이 기본값보다 얼마나 많은지로 본다.

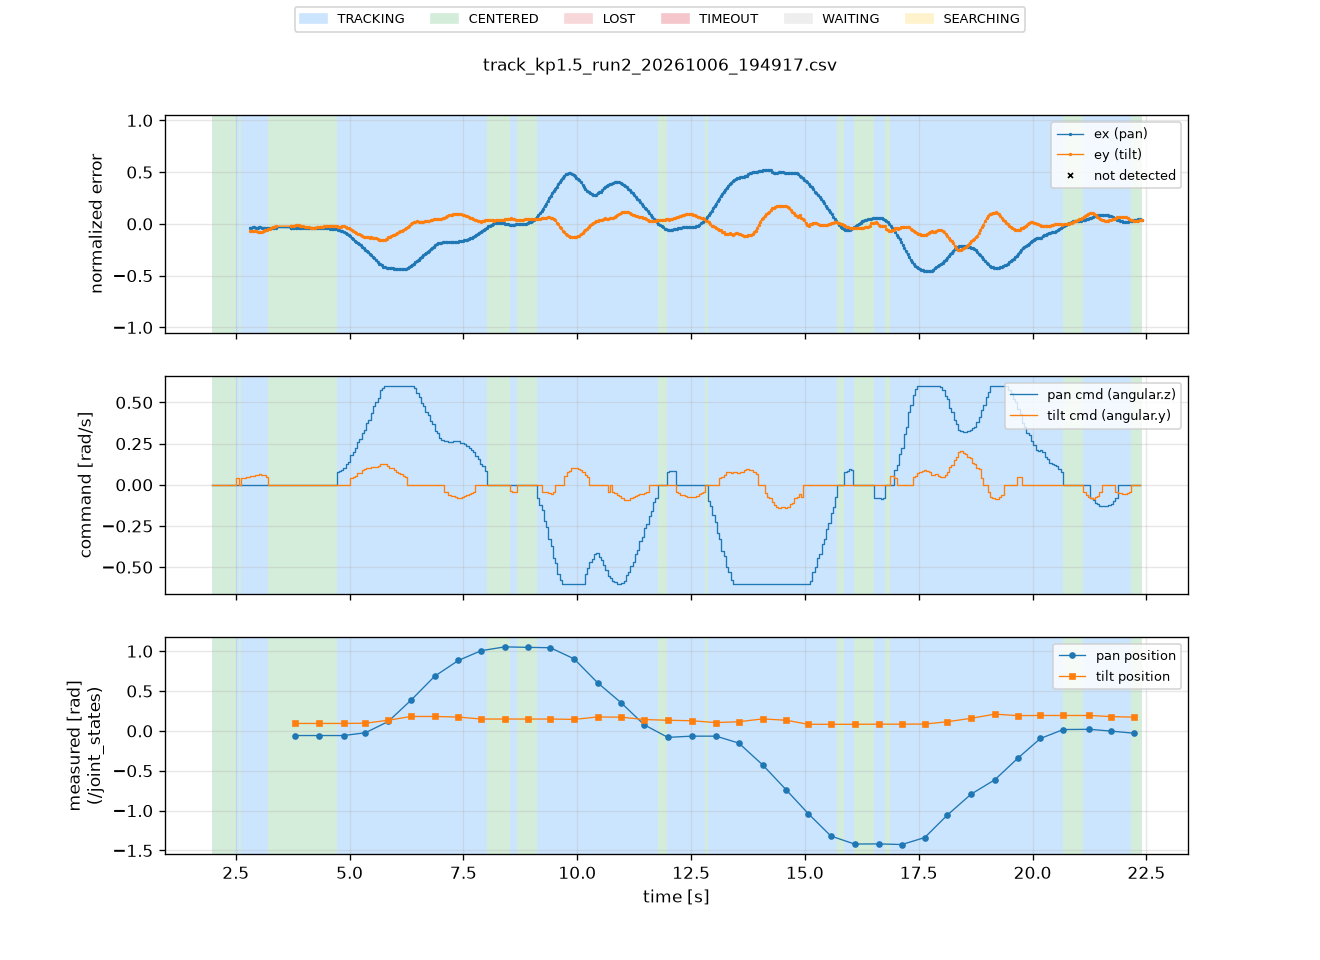
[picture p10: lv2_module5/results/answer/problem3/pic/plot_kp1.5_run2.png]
Kp 1.5 run2


*Kp 1.5 run2 — 위: ex·ey, 가운데: 팬·틸트 명령, 아래: `/joint_states` 실제 각도(약 2 Hz, 점). 배경색이 상태 구간. 이동 구간에서만 0.6 rad/s로 포화하고 중심 근처에서는 반전이 작다*

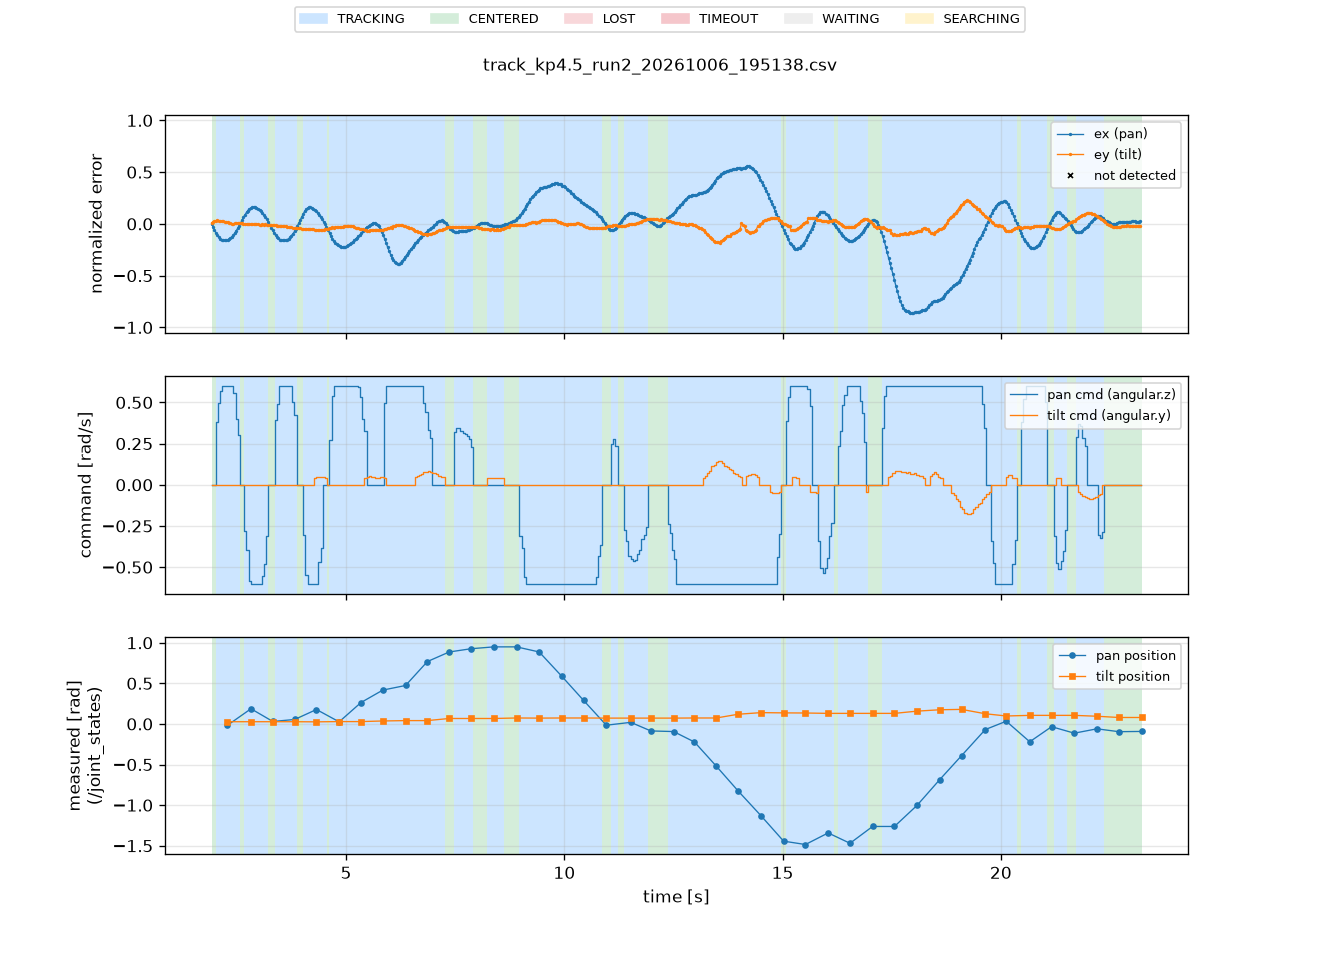
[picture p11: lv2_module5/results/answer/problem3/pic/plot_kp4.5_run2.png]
Kp 4.5 run2


*Kp 4.5 run2 — 같은 구성. 2 ~ 7 s와 15 ~ 22 s에서 ex가 중심을 오가고 팬 명령이 +0.6 ↔ −0.6으로 번갈아 나간다(부호 반전 7.0회 / 10 s)*

원본: `bags/<회차>/*.mcap`, CSV `bags/csv/track_kp*.csv`, 요약 `bags/plots/track_summary.csv`, 전체 회차 그래프 `bags/plots/track_kp*.png`.
**명령과 실제 각도는 서로 다른 그래프에 그렸다.** 실제 각도는 `/joint_states` 실측이며 약 2 Hz라 점으로 표시했다 — 명령을 실제 위치처럼 표시하지 않았다.

## 3.5 실제 추적 영상

Kp 1.5 추적

*Kp 1.5 — 포화 비율 0.35, 최대 \|ex\| 0.52 ~ 0.62로 가장 안정적이었던 설정*

Kp 2.0 추적

*Kp 2.0 — 포화 비율 0.51*

Kp 2.5 추적

*Kp 2.5 — 포화 비율 0.60*

GIF·MP4는 Git LFS로 보관하므로 저장소를 받은 뒤 `git lfs pull`을 해야 실제 파일이 열린다.

## 3.6 해석

1. Kp = 4.5_run1은 검출 출력 비율 47%, 제외 684프레임으로, 중심을 지나쳐 목표를 화면 밖으로 놓친 구간이 길었다. RMSE(0.124)가 낮게 나온 것은 놓친 프레임이 계산에서 빠졌기 때문이므로 좋은 결과로 해석하지 않는다.
2. Kp = 1.5는 run2·3 기준 포화 비율과 최대 |ex|가 가장 낮고 검출이 안정적이었다. 흔들림(부호 반전)은 1.5 ~ 2.5 사이에서 차이가 없어(run2·3 평균 2.4 ~ 3.1회) 선택 근거로 쓰지 않았다. 현재 speed_limit 0.6 rad/s에서는 Kp 1.5 ~ 2.5 범위가 적절하고, 4.5는 놓침 위험이 있다.
3. 응답 지연 요인: 카메라 → 검출 → controller(20 Hz) → control(최대 20 Hz 전송) → 펌웨어(가속 0.3 s). 정지 시에는 데드밴드 경계(|ex| ≈ 0.05 → 0.05 × 35° ≈ 1.8°)에서 멈춘다.
4. RMSE와 달리 흔들림은 Kp에 따라 갈린다. 같은 조건(run2·3)에서 Kp = 4.5의 부호 반전은 10 s당 6.7 ~ 7.0회로, 다른 Kp(2.4 ~ 3.6회)의 약 2배다. 조건이 다른 run1을 넣어도 4.5(4.3회)가 다른 Kp의 최댓값(3.6회)보다 많아 결론은 같다. 그래프에서도 4.5는 중심 근처에서 ±0.6 rad/s 명령이 좌우로 번갈아 나가는 진동이 보인다. 중심 근처 RMS는 0.10 ~ 0.16으로 Kp마다 뚜렷한 차이가 없어(4.5 run1의 0.096이 가장 낮지만 run2·3은 0.118 ~ 0.128), Kp를 올려도 중심 오차는 줄지 않고 흔들림만 늘었다.

---

# 4. 문제 4 — 성능 측정과 소실 복구

## 4.1 구현 내용 — 상태와 전이

| 발제 상태 | 구현 상태 | 조건 | 동작 |
| --- | --- | --- | --- |
| IDLE | `WAITING` | 시작 후 아직 신선한 입력 없음 | 정지 명령 |
| IDLE | `IDLE` | `/tracking_enable` = false(명시적 중지) | 정지. true가 되면 복귀 절차부터 |
| TRACKING | `TRACKING` / `CENTERED` | 신선한 입력에서 검출(z > 0) / 두 축 모두 데드밴드 안 | 제한 범위 안에서 P 제어 / 정지 |
| LOST | `LOST` | 신선한 입력에서 미검출(z = 0) | **첫 프레임부터** 정지. 이전 속도·좌표 유지 없음(표시 유예도 두지 않았다) |
| LOST | `TIMEOUT` | 마지막 신선한 입력 후 0.5 s, 또는 촬영 시각이 0.5 s보다 오래됨 | 정지 |
| TRACKING 복귀 | `LOST` → `TRACKING` | **신선한 목표 연속 3프레임** 검출(`recover_frames: 3`, 30 fps ≈ 0.1 s). 중간에 미검출이 끼면 처음부터 | 그동안 정지, 이후 같은 속도 상한 안에서 재개 |

정지 보장 :

- control: `/cmd_vel`이 0.5 s 동안 없으면 `v 0 0` 전송
- OpenCR V3 펌웨어: 속도 명령이 500 ms 동안 갱신되지 않으면 스스로 정지
- 속도 명령은 위치 목표로 구현되어 있으나, 정지는 "목표 갱신 중단"이 아니라 펌웨어가 현재 위치를 목표로 다시 쓰는 방식이다. 실제 정지는 3.4절 제어 통신 중단 시험으로 확인한다.

시야 밖 탐색은 하지 않았다. 기본 복구 = 시야 안 재등장 재검출.

설정: Kp = 1.5 (문제 3에서 RMSE·포화 비율이 가장 낮았던 값), Kp_tilt 0.8, 속도 상한 0.6 / 0.4 rad/s, 데드밴드 0.05, 명령 20 Hz, 입력 타임아웃 0.5 s.

## 4.2 구현 내용 — 정지 보장 네 겹

| 끊기는 곳 | 감지 | 결과 |
| --- | --- | --- |
| 카메라 → 인지 | 0.3 s 새 영상 없음 | `CAMERA_STALL`, `/target` 발행 중단 |
| 인지 → 제어 | 0.5 s 신선한 입력 없음 | `TIMEOUT`, 두 축 0을 계속 발행 |
| 제어 → 구동 | 0.5 s `/cmd_vel` 없음 | `v 0 0` 전송 |
| 구동 → 모터 | OpenCR 펌웨어: 속도 명령 500 ms 미갱신 | 펌웨어가 스스로 정지  |
|  |  |  |

## 4.3 시험 방법·판정 기준

| 시험 | bag | 방법 |
| --- | --- | --- |
| 정상 추적 | `p4_normal` | 30 s 이상 퍽을 움직이며 추적 |
| 가림 후 재등장 | `p4_occl` | 추적 중 손으로 약 2 s 가렸다가 치우기 5회 |
| 인지 입력 중단 | `p4_input` | 추적 중 인지 프로세스 종료 |
| 제어 통신 중단 | `p4_ctrl` | 모터가 회전하는 중 제어 프로세스 `kill -9`, 모터 정지를 영상으로 확인 |

기록 토픽: `/target /cmd_vel /tracking_status /joint_states /perception_status`.

분석(PC): bag 재생 → `track_logger` CSV → `track_recovery`(이벤트·복구 시간) · `track_plot`(FPS·RMSE).

이벤트 판정 (`track_recovery`):
- 소실 시각 = 상태가 TRACKING·CENTERED → LOST·TIMEOUT으로 바뀐 시각
- 정지 = 그 뒤 첫 `/cmd_vel`이 팬·틸트 모두 0
- 재등장 시각 = 그 뒤 처음 검출된 `/target`

- 복귀 시각 = 재등장 뒤 처음 TRACKING·CENTERED

- 복구 시간 = 복귀 − 재등장, 3 s 이내면 성공

## 4.4 측정 결과 — 필수 시험 4종

네 시험 모두 영상을 남겼다(`problem4/gif/`, Git LFS). 영상은 동작 확인용이고, 아래 수치는 모두 bag·CSV에서 계산한 값이다.

### 정상 추적 (`p4_normal`, 42.5 s — 발제 기준 30 s 이상)

정상 추적

| 지표 | 값 |
| --- | --- |
| 처리 FPS | 29.98 (카메라 설정 30 fps와 구분) |
| 검출 출력 비율 (`detected=true` 비율) | 76.4% (1,274프레임 중 z > 0) — **정답 대조 검출률과 다르다**(4.5절) |
| 수평 RMSE (ex) | 0.247 — 사용 938 / 제외 336, 추적 구간 비율 96.4% |
| 수직 RMSE (ey) | 0.407 |
| 최대 |ex| | 0.953 |
| 소실 | 11회, 그중 10회 복구(0.07 ~ 0.32 s). 1회는 녹화 종료로 판정 불가 |

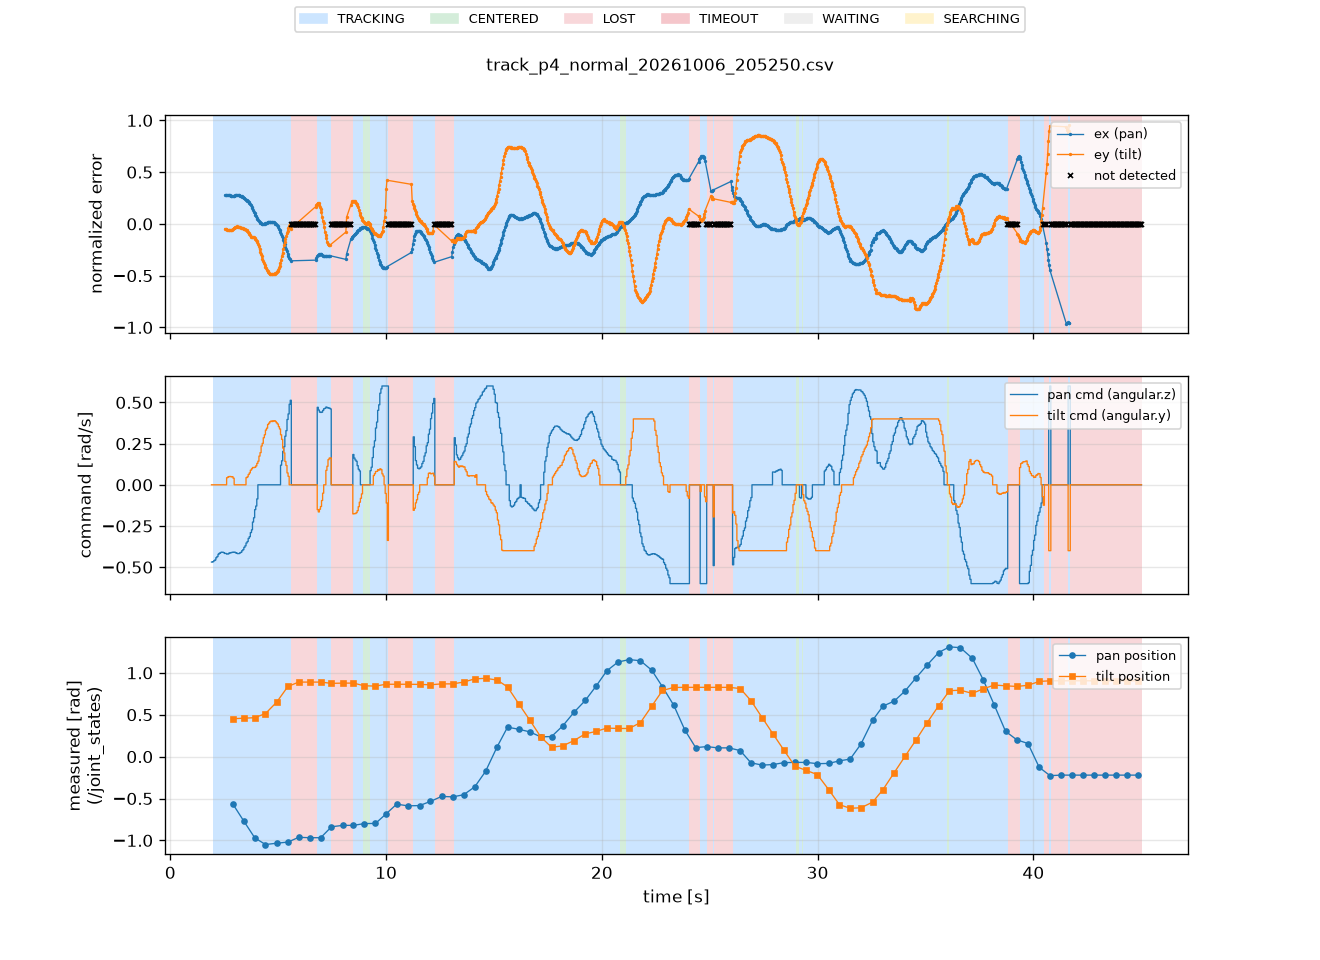
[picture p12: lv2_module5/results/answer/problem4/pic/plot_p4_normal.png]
정상 추적 그래프


**정상 추적 — 위: ex·ey(× = 미검출), 가운데: 팬·틸트 명령, 아래: `/joint_states` 실제 각도(약 2 Hz). 배경색은 상태(파랑 TRACKING, 분홍 LOST). 15 s 이후 ey가 ±0.5 ~ 0.85까지 커지고 틸트 명령이 ±0.4 rad/s 상한에 자주 걸린다**

### 가림 후 재등장 (`p4_occl`) — 약 2 s를 목표로 가림(실제 1.7 ~ 3.8 s) 후 시야 안 재등장, 5회

가림 후 재등장

| 회 | 소실 [s] | 정지까지 [s] | 재등장 [s] | 가림 시간 [s] | 복귀 [s] | 복구 시간 [s] | 판정 |
| --- | --- | --- | --- | --- | --- | --- | --- |
| 1 | 10.614 | 0.050 | 12.561 | 1.95 | 12.663 | 0.102 | 성공 |
| 2 | 17.114 | 0.049 | 20.899 | 3.79 | 21.015 | 0.116 | 성공 |
| 3 | 25.417 | 0.046 | 29.135 | 3.72 | 29.215 | 0.080 | 성공 |
| 4 | 33.263 | 0.051 | 35.668 | 2.41 | 35.767 | 0.099 | 성공 |
| 5 | 40.812 | 0.051 | 42.540 | 1.73 | 42.664 | 0.124 | 성공 |
- **복구 성공률 5/5 = 100%**, 복구 시간 평균 **0.104 s**(0.080 ~ 0.124 s). 실패 회차 없음.
- 5회 모두 소실 후 **다음 명령 주기(≤ 0.05 s) 안에** 정지 명령이 나갔다.
- 가림 시간이 3.7 ~ 3.8 s였던 2·3회의 복구 시간도 0.116·0.080 s로 늘지 않았다 — 가림 길이는 복구 시간과 무관하다.

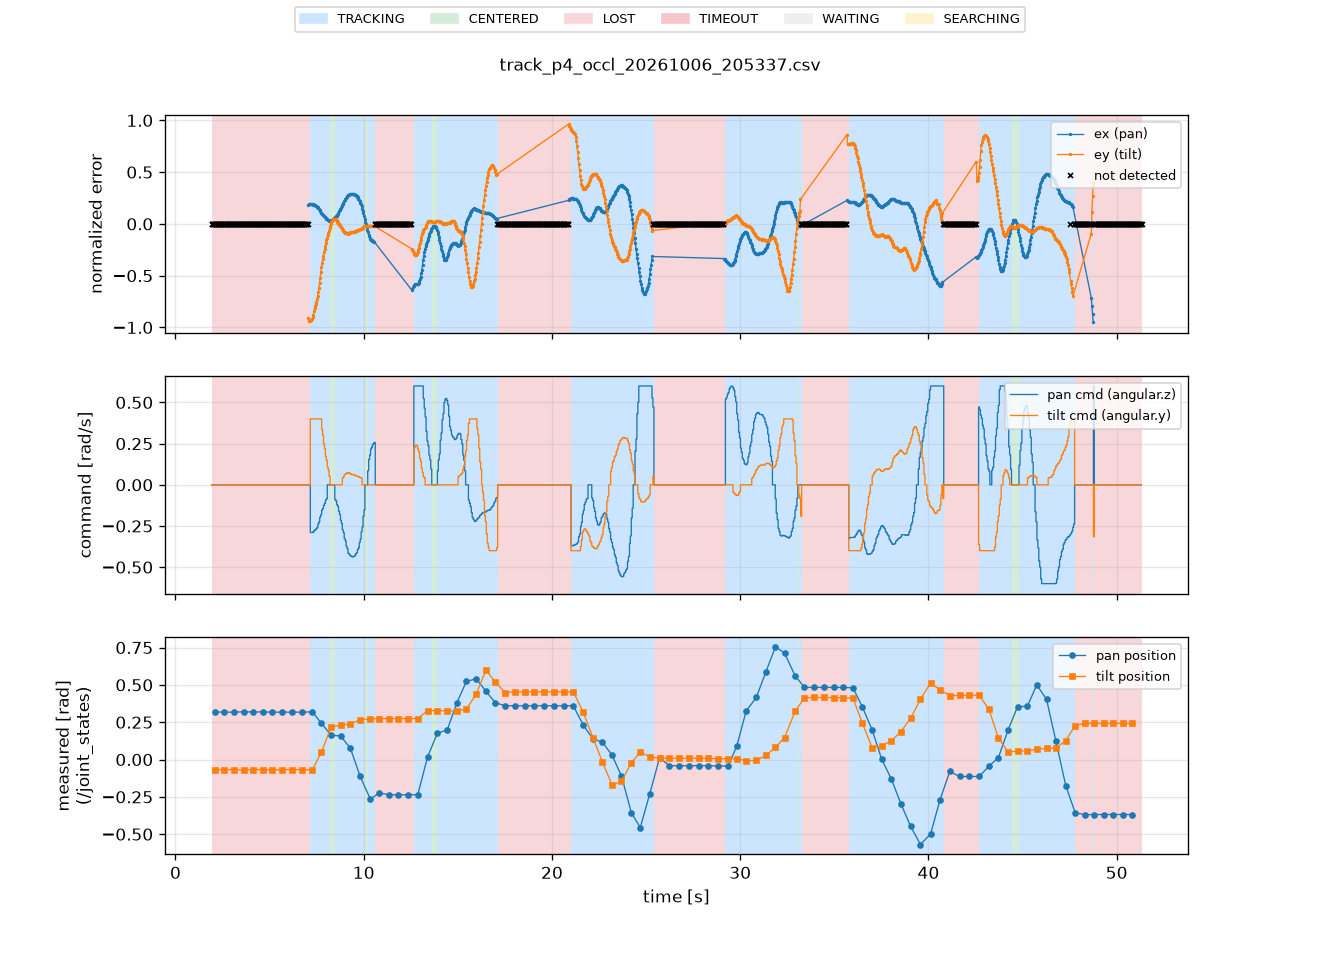
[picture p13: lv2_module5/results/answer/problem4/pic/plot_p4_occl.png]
가림 후 재등장 그래프


**가림 후 재등장 — 분홍(LOST) 구간마다 팬·틸트 명령이 0으로 떨어지고 실제 각도가 평평하게 유지된다. 시작 0 ~ 7 s의 LOST는 시험 시작 전(목표를 아직 보여주지 않음)이다**

### 인지 입력 중단 (`p4_input`) — 추적 중 인지 프로세스 종료, 1회

인지 입력 중단

| 마지막 입력 [s] | TIMEOUT [s] | 타임아웃까지 [s] | 정지 명령 |
| --- | --- | --- | --- |
| 13.155 | 13.696 | 0.541 | 다음 주기(0.050 s) 안에 0 |

설정 0.5 s + 명령 주기(0.05 s) 안에서 TIMEOUT으로 바뀌고 정지 명령을 냈다. 이후 controller가 재시작될 때(56.2 s, WAITING)까지 약 42.5 s 동안 /cmd_vel 594개가 모두 0이었다.

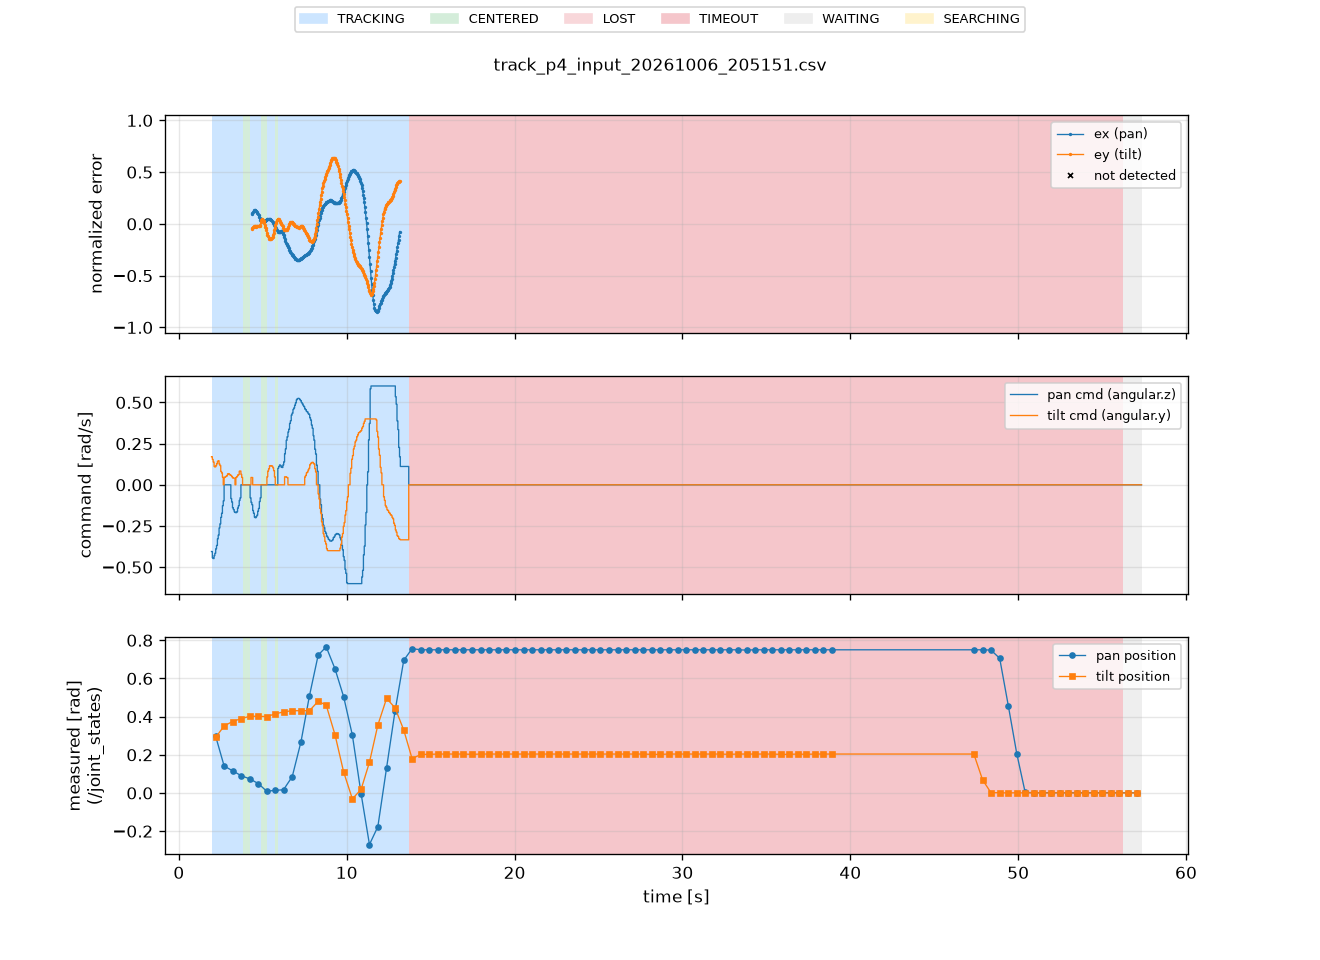
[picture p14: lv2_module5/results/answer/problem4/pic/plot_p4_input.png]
인지 입력 중단 그래프


**인지 입력 중단 — 13.7 s부터 TIMEOUT(진한 분홍), 명령은 0으로 유지되고 실제 각도도 팬 0.75 rad·틸트 0.21 rad에서 멈춰 있다. 48 ~ 50 s에 각도가 0으로 움직인 것은 명령이 0인 동안이므로 `/cmd_vel`에 의한 것이 아니다**

### 제어 통신 중단 (`p4_ctrl`) — 회전 중 제어 프로세스를 `kill -9`, 1회 · **미완**

제어 통신 중단

이 영상이 유일한 판정 수단이다 — 아래 표의 "모터 정지"는 이 영상에서 멈춘 시각을 읽어 채워야 한다.

| 항목 | 값 |
| --- | --- |
| control 종료 시각 | 22.09 s (마지막 `/joint_states`) |
| 종료 후 `/cmd_vel` | 제어 노드는 살아 있어 27.07 s(기록 끝)까지 명령을 계속 발행했다 — 받는 쪽이 없으므로 정지는 전적으로 펌웨어 워치독에 달려 있다 |
| 모터 정지 | 영상(`problem4/gif/stop.gif`)은 첨부했으나 **정지 여부·정지까지 시간 판정이 아직 기록되지 않았다**. 펌웨어 워치독 500 ms 이내 정지 예상 |
|  |  |

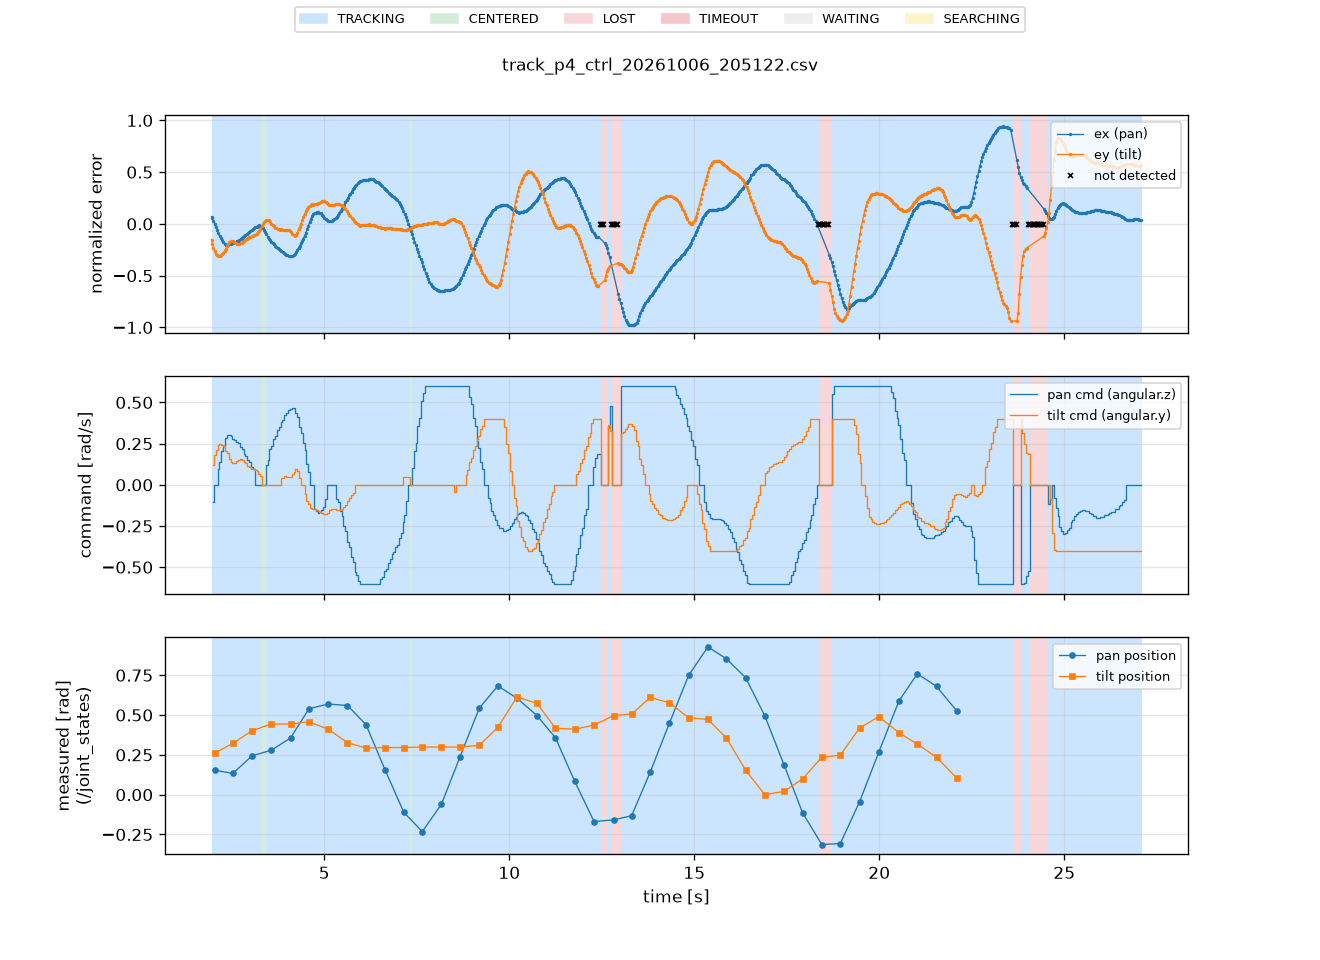
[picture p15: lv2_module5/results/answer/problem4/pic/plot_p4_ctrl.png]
제어 통신 중단 그래프


**제어 통신 중단 — 아래 그래프의 실제 각도가 22.1 s에서 끊긴다(control 종료). 가운데 그래프에서 그 뒤에도 tracker 명령은 계속 나가고, 25 s 이후 틸트 −0.4 rad/s 포화 명령에도 위 그래프의 ey가 거의 변하지 않는다**

## 4.5 측정 결과 — 지표와 평가 프레임

| 지표 | 계산 | 결과 | 기록 조건 충족 |
| --- | --- | --- | --- |
| 처리 FPS | 처리 완료 프레임 수 / 실제 경과 초 | **29.98** | 카메라 설정 30 fps와 구분해 적었다 |
| 검출률 | 올바른 검출 / 목표가 실제 보이는 평가 프레임 × 100 | **95 / 100 = 95%** | 10프레임마다 1장씩 고르게 100장(최소 30장) · 목록 저장 |
| 배경 오검출 | 목표 없는 평가 프레임의 잘못된 검출 수 | **0 / 105 = 0%** | 105장(최소 10장) · 검출률과 별도 기록 |
| 수평 RMSE | sqrt(mean(ex²)) | **0.247** | 사용 938 / 제외 336, 추적 구간 비율 96.4% 병기 |
| 복구 성공률 | 재등장 후 3 s 이내 TRACKING 복귀 / 5 × 100 | **100%** | 3 s는 판정 기준일 뿐 합격선이 아님 |
| 복구 시간 | 복귀 시각 − 재등장 시각 | **평균 0.104 s** (0.080 ~ 0.124) | 실패 회차 없음. 실패는 0초가 아닌 실패로 표기 |

**평가 프레임 목록:** `problem4/frames/evaluation_frames.csv` (205행 — 파일명, 노드 검출 플래그, 사람 판정, 비고).

- `p4_normal2` 100장: 약 33 s 동안 목표가 계속 화면 안. 검출 95 / 미검출 5.
- `p4_empty` 105장: 같은 장소에서 큐브만 치운 장면. 노드 검출 0건 → **오검출 0은 전수 확인**(검출 플래그가 전부 0).
- **미검출 5장은 전수 사람 판정**했다. 모두 큐브가 보이는데 놓친 경우이고, 3장 + 2장의 연속 구간 두 곳에 몰려 있다. 두 구간 모두 천장 형광등·창을 배경으로 큐브를 들어 올린 역광 장면으로, 마스크가 큐브 일부만 남아 면적·모양 조건에서 탈락했다.
- **검출 95장 중 사람 판정은 3장(표본)만** 했고 모두 큐브에 정확히 맞았다(예: `…354150720000_1.jpg` ex=−0.516 ey=−0.721 Z=0.374 m size=2.8×6.4 cm). 나머지 92장은 목록에 `unverified`로 남겼다 — 95%는 "나머지 92장이 모두 올바른 검출"이라는 가정 위의 **상한값**이다.

**지연:** 영상 수신 → 명령 생성 지연과 모터의 실제 반응 시간은 측정하지 않았다. 3.6절 해석 5의 지연 사슬은 설정값에서 계산한 **설계 추정치**이고, 촬영→구동 지연으로 보고하지 않는다.

## 4.6 해석

1. **소실 대응은 설계대로 동작했다.** 가림 5회 모두 다음 명령 주기(≤ 0.05 s) 안에 정지했고 0.08 ~ 0.12 s 만에 복귀했다. "이전 속도를 유지하다 천천히 멈추는" 동작은 없다 — 미검출 첫 프레임부터 0을 보낸다.
2. **복구 시간은 거의 전부 복귀 조건 비용이다.** 0.104 s ≈ 연속 3프레임(0.1 s) + 명령 주기. 재검출 자체는 지연을 거의 만들지 않으므로, `recover_frames`를 조절하면 복구 시간과 잘못된 재개 위험을 직접 맞바꿀 수 있다.
3. **입력이 끊기면 0.541 s에 정지한다.** 설정값 0.5 s + 명령 주기 0.05 s와 정확히 맞는다.
4. **실패 원인은 검출 쪽에 있다.** 정상 추적의 `detected=true` 비율 76%는 "화면 밖으로 나갔다"가 아니다. 소실 직전 ex가 ±0.3 ~ 0.4로 화면 안쪽이었고, 명령·상태 전이는 전 구간 정상이었으며, 비슷한 조건에서 따로 측정한 사람 대조 검출률은 95%다. 즉 통신·제어가 아니라 **움직임 중 모션 블러와 역광으로 마스크가 무너진 순간**이 끊김의 주된 원인이다. 다만 두 자료는 다른 회차라 수치를 직접 비교할 수는 없다.
5. **수직 RMSE(0.407)가 수평(0.247)보다 크다.** 틸트는 Kp 0.8·상한 0.4 rad/s로 팬보다 느리고, 세로 화각이 좁아 같은 각도 변화가 더 큰 정규화 오차로 나타난다. 퍽을 상하로 크게 움직인 영향도 섞여 있어 분리하지 못했다.

---

# 5. 문제 5 — bag 재현

작성 2026-10-08. **이 장만 다른 구성에서 측정했다** — 보드 작업본(기준 커밋 `74984e3` 계열, `tracker_type: fusion`)이고,
1 ~ 4장의 `target_detector`와 검출기가 다르다. 수치를 1 ~ 4장과 직접 비교하지 않는다(5.5절 해석 4).

## 5.1 구현 내용 — 기록·재현 방식

| 항목 | 내용 | 위치 |
| --- | --- | --- |
| 기록 | 대표 성공 장면·소실/복귀 장면을 영상·뎁스·목표·명령·관절 토픽과 함께 기록 | ` ~/bags/p5_success`, ` ~/bags/p5_loss_return` |
| 메타데이터 | bag마다 `metadata.yaml` + `bag_info.txt`(해상도·토픽·메시지 수·기간) + 실행 당시 설정 3종 + `uncommitted.diff` | 각 bag 폴더 |
| 입력 재처리 | bag 영상만 재생 → `tracker_node`로 다시 검출 → `/target_replay` 등 별도 토픽으로 기록 | ` ~/bags/p5_*_replay` |
| 결과 재분석 | 저장된 `/target`·`/cmd_vel`에서 FPS·검출 출력 비율·RMSE·소실 이벤트 재계산, 재처리 결과와 프레임별 대조 | `replay_info.txt`, `compare.csv` |
| 다른 팀원 실행 | 다른 PC에서 `p5_success` 입력 재처리 + RViz 확인(부분 구간) | 5.4절 |

**두 재현의 차이**를 분명히 나눴다. 기록된 `/target`을 보기만 한 것은 입력 재처리가 아니다.

|  | 입력 재처리 | 결과 재분석 |
| --- | --- | --- |
| 입력 | bag의 **영상**(컬러·뎁스·camera_info) | bag의 **저장된 출력**(`/target`·`/cmd_vel`) |
| 검출기 실행 | 함 (현재 코드·설정) | 안 함 |
| 확인하는 것 | 검출·제어 코드가 같은 입력에 같은 결과를 내는가 (코드 회귀) | 당시 기록으로 계산한 지표가 성능표와 같은가 (계산 재현) |
|  |  |  |

두 재현 모두 **모터 출력 없이** 수행했다(PC에서 control 미실행, 보드 연결 없음). 오프라인 재현이며 실제 하드웨어 폐루프 시연과 다르다.

입력 재처리 명령은 세 가지를 지킨다 — ① `--topics`로 영상만 재생해 저장된 `/target`·`/cmd_vel`이 섞이지 않게 하고,
② 출력은 `/target_replay`·`/cmd_vel_replay`·`/perception_status_replay`로 remap하며,
③ `--clock-topics`로 촬영 시각을 `/clock`에 싣고 tracker를 `use_sim_time:=true`로 띄워 타임아웃·지연에 현재 벽시계가 섞이지 않게 한다.

```bash
# 터미널 1 — 검출기 (원본과 섞이지 않게 remap, bag 시간 사용)
ros2 run xmen_tracker tracker_node --ros-args \
  --params-file ~/bags/p5_success/tracker.yaml \
  -p detector_config:=$HOME/bags/p5_success/detector.yaml \
  -p use_sim_time:=true \
  -r /target:=/target_replay -r /cmd_vel:=/cmd_vel_replay \
  -r /perception_status:=/perception_status_replay

# 터미널 2 — 영상만 재생, 촬영 시각을 /clock으로
ros2 bag play ~/bags/p5_success --clock-topics /camera/color/image_raw \
  --qos-profile-overrides-path <QoS override> \
  --topics /camera/color/image_raw /camera/aligned_depth_to_color/image_raw /camera/color/camera_info

# 터미널 3 — 재처리 결과 기록
ros2 bag record -s mcap -o ~/bags/p5_success_replay \
  /target_replay /cmd_vel_replay /perception_status_replay
```

## 5.2 기록한 bag

| 항목 | 값 |
| --- | --- |
| 해상도 / 카메라 FPS / 형식 | 640 × 360 (컬러·정렬 뎁스) / 30 / mcap |
| 검출 설정 | `detector.yaml` — H 104 ~ 120 · S 200 ~ 255 · V 8 ~ 255 (1.2절과 같음) |
| 추적 설정 | `tracker.yaml` — **`tracker_type: fusion`**, Kp 1.5 / 1.2, 데드밴드 0.05, 속도 상한 0.9 / 0.6 rad/s, **처리 15 Hz**, 명령 20 Hz, 타임아웃 0.5 s |
| 구동 설정 | `control.yaml` — `control_lite`, 115200 baud, 시작 시 홈 복귀 |
| 기준 커밋 | **미기록** — `bag_info.txt`의 기준 커밋 칸이 비어 있다. `uncommitted.diff`는 0 byte라 작업 트리는 깨끗했다 |

두 bag의 설정 3종은 같다(`diff` 확인).

| bag | 장면 | 기간 [s] | 크기 | 메시지 수 |
| --- | --- | --- | --- | --- |
| `p5_success` | 대표 성공 | 47.81 | 912.0 MiB | 4,864 |
| `p5_loss_return` | 소실·복귀 | 29.48 | 575.0 MiB | 3,101 |

토픽별 메시지 수(`p5_success` / `p5_loss_return`): 컬러 594/374 · 정렬 뎁스 591/373 · camera_info 592/374 ·
`/target` 353/247 · `/cmd_vel` 418/326 · `/perception_status` 42/54 · `/joint_states` 2,274/1,353.
mcap 4개의 SHA-256은 `problem5/report_problem5.md`에 전문이 있다.

### 5.2.1 bag 메타데이터

| bag | 장면 | 기간 [s] | 크기 | 메시지 수 | SHA-256 (mcap) |
|---|---|---|---|---|---|
| `p5_success` | 대표 성공 | 47.81 | 912.0 MiB | 4864 | `f2d9a2c3…8b7594638` |
| `p5_loss_return` | 소실·복귀 | 29.48 | 575.0 MiB | 3101 | `34fc72b6…1e63938` |

## 5.3 재현 결과

### 대표 성공 (`p5_success`)

| 지표 | 원본 `/target` (결과 재분석) | 재처리 `/target_replay` (입력 재처리) |
| --- | --- | --- |
| 프레임 수 | 353 (47.13 s) | 382 (47.75 s) |
| 처리 FPS | 7.47 | 7.98 |
| 검출 출력 비율 | 87.8% (310 / 353) | 92.1% (352 / 382) |
| 수평 RMSE (ex) | 0.079 (검출 310) | 0.080 (검출 352) |
| 수직 RMSE (ey) | 0.110 | 0.128 |
| 최대 |ex| | 0.355 | 0.357 |
| 소실 | 8회 | 6회 |

같은 촬영 시각 프레임 대조(`compare.csv`): 짝 프레임 222, **검출 여부 일치 95.0%**(211/222, 불일치 11개는 모두 원본 미검출 → 재처리 검출),
둘 다 검출한 196개의 **|Δex| 평균 0.0006 / 최대 0.0054**.

### 소실·복귀 (`p5_loss_return`)

| 지표 | 원본 `/target` (결과 재분석) | 재처리 `/target_replay` (입력 재처리) |
| --- | --- | --- |
| 프레임 수 | 247 (29.08 s) | 242 (27.62 s) |
| 처리 FPS | 8.46 | 8.72 |
| 검출 출력 비율 | 40.5% (100 / 247) | 42.1% (102 / 242) |
| 수평 RMSE (ex) | 0.124 (검출 100) | 0.078 (검출 102) |
| 수직 RMSE (ey) | 0.356 | 0.297 |
| 최대 |ex| | 0.985 | 0.130 |
| 소실 | 18회 (마지막 1회 재검출 없음) | 8회 (마지막 1회 재검출 없음) |
| 소실 후 정지까지 | 0.001 ~ 0.027 s | 0.000 s |

같은 촬영 시각 프레임 대조: 짝 프레임 143, **검출 여부 일치 81.8%**(117/143, 불일치 26개 = 원본만 검출 7 · 재처리만 검출 19),
둘 다 검출한 41개의 **|Δex| 평균 0.0010 / 최대 0.0042**.

원본의 긴 소실(6번, 약 6.0 s)과 재처리의 긴 소실(1번, 약 8.0 s)이 같은 구간(t ≈ 1791422644.6 ~ 652.6)에 있어, 의도한 가림 구간은 양쪽 모두 소실로 잡혔다.

## 5.4 다른 팀원 실행

| 항목 | 값 |
| --- | --- |
| PC | `pa8-Legion-Pro-5-16IAX10` |
| 날짜 | 2026-10-08 14:53 KST |
| 실행 내용 | `p5_success` 입력 재처리 + RViz 확인, 0 ~ 16.65 s 구간 |
| 결과 | 검출·추적 표시 확인, 처리 약 12 ~ 15 FPS (보드 원본 7.47 FPS) |
| 검출 설정 로드 | HSV [104,200,8] ~ [120,255,255], min_area 57 px, depth 0.1 ~ 1.1 m — `detector.yaml`과 같음 |
| sim time | `now`가 bag 시각을 따라감, `stale 0` |
| 원본 로그 | problem5/third_party_log.txt |

5.3절의 재처리는 작성자 본인 PC에서 한 것이라 이 표에 넣지 않았다.

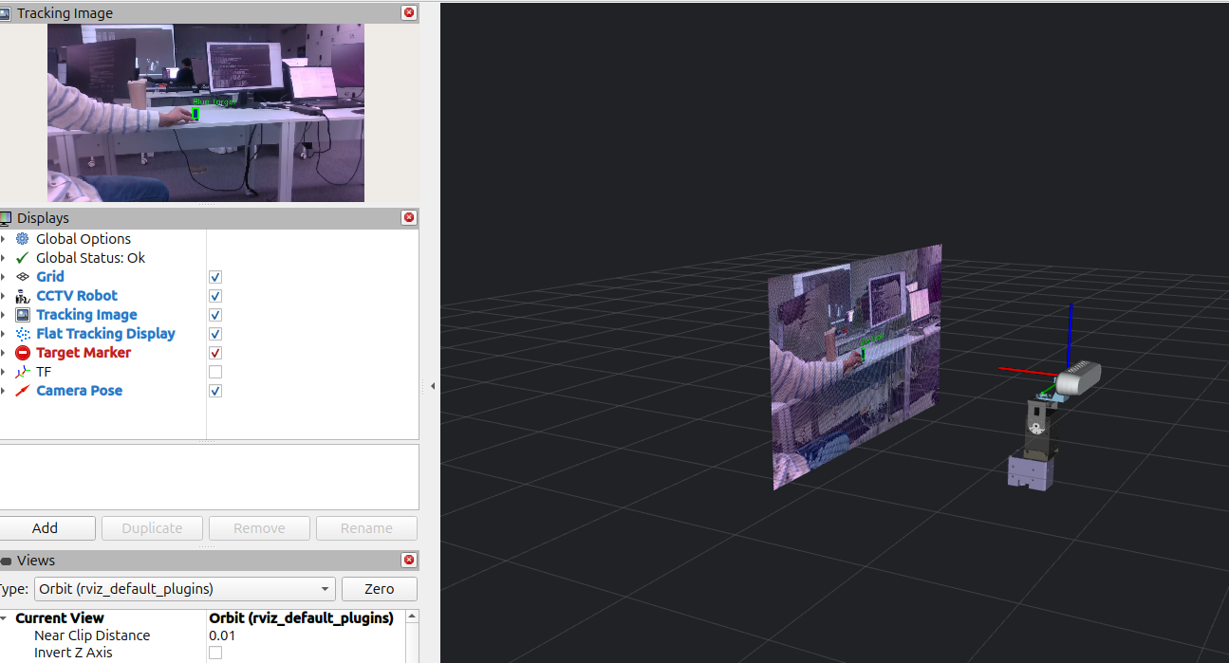
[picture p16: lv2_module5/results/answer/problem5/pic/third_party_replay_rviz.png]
다른 PC 재처리 — RViz


*다른 PC에서 `p5_success`를 재처리 중인 RViz. 왼쪽 위 Tracking Image에 큐브 검출 박스, 오른쪽에 로봇 모델과 이미지 평면*

| 항목 | 값 |
|---|---|
| 검출 설정 로드 | HSV [104,200,8] ~ [120,255,255], min_area 57 px, depth 0.1 ~ 1.1 m — `detector.yaml`과 같음 |
| sim time | `now`가 bag 시각(1791422034 ~ 046 s)을 따라감, `stale 0` |
| 처리량 (2 s마다) | 동기화 40 ~ 45쌍 중 24 ~ 30개 처리 → 약 12 ~ 15 FPS |

## 5.5 해석

1. ****검출기 자체는 재현된다.**** 두 bag 모두 원본·재처리가 함께 검출한 프레임에서 |Δex| 최대 0.0054로, 같은 영상·같은 설정이면 중심 오차는 사실상 같다.

2. ****차이는 "어떤 프레임을 처리했는가"에서 나온다.**** 짝 프레임이 원본 프레임의 63%(222/353)·58%(143/247)뿐이다. tracker가 15 Hz로 가장 최근 프레임만 처리하므로(`tracking_hz: 15`) 보드와 PC에서 건너뛴 프레임이 달라진다. fusion 추적기는 KCF·SIFT 상태를 이어 쓰므로, 처리한 프레임이 다르면 다음 프레임의 검출 여부도 달라질 수 있다. 소실·복귀 bag에서 불일치(18.2%)가 큰 것은 목표가 가려지고 나타나는 경계 프레임이 많기 때문으로 보인다.

3. 소실·복귀 bag의 최대 |ex|가 0.985 → 0.130으로 크게 다른 것은 원본의 한 프레임(8.49 s) 때문이다. 화면 왼쪽 끝 모니터 가장자리를 면적비 0.0005로 잘못 검출한 배경 오검출이다

4. 명령 수가 원본 418 vs 재처리 961로 다르다. 원본은 기록 공백(약 21.4 s) 동안 명령이 거의 없었고(5개), 공백을 빼면 약 16 Hz(명령 간격 중앙값 0.062 s)였다. 재처리는 PC에서 sim time 기준 20 Hz 타이머가 그대로 돌았다. 공백을 뺀 나머지 차이(16 vs 20 Hz)는 보드 부하로 타이머가 밀린 것으로 보인다.

5. 원본 `/target`의 수신 − 촬영 시각은 중앙값 0.25 s / 0.17 s, 최대 0.41 s / 0.47 s였다(`p5_success` / `p5_loss_return`). 입력 신선도 한계 `max_input_age` 0.5 s에 가까워, 보드 부하가 조금만 늘어도 신선한 입력이 TIMEOUT으로 처리될 수 있다.

6. 소실 중 정지는 실제 모터로 확인된다. `p5_loss_return`의 의도한 가림(2.46 ~ 8.49 s, 6.0 s) 동안 마지막 명령으로 틸트가 0.006 rad 더 움직인 뒤(2.46 ~ 2.52 s), 나머지 구간은 팬·틸트 모두 0.003 rad 이내로 멈춰 있었다. `p5_success`의 미검출 구간(32.1 ~ 33.8 s)도 팬 0.002 rad, 틸트 0 rad 변화였다(`/joint_states` 48 Hz 기준).

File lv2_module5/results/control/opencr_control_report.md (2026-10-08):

# opencr_control.ino 코드 설명 보고서

date: 2026-10-03

Pi: pa06

## 개요

opencr_control.ino(493줄, 버전 `OPENCR_CONTROL_V2`)는 OpenCR 보드에서 도는 펌웨어입니다. 라즈베리파이의 main.py가 보낸 글자 명령을 해석해 다이나믹셀 모터 두 대(XM430-W350)를 움직입니다.

| 축 | 모터 ID | 홈 위치(엔코더 틱) | 허용 범위 |
|---|---|---|---|
| X축(좌우, pan) | 11 | 0 | 홈 기준 ±180° |
| Y축(상하, tilt) | 12 | 2048 | 홈 기준 ±135° |

코드 안에서는 배열 순서가 **Y축이 0번, X축이 1번**입니다. 사용자가 입력하는 순서(X 먼저)와 반대라서 읽을 때 주의해야 합니다. 모터 한 바퀴는 4096틱이고, 1°는 약 11.4틱입니다.

아두이노 스케치라서 `setup()`은 전원을 켤 때 한 번, `loop()`는 그 뒤로 계속 반복합니다. 나머지 함수는 모두 이 두 함수가 부르는 부품입니다. C++에서는 함수 안에 함수를 만들 수 없어서, 부품 함수들은 `loop()` 밖에 정의되어 있습니다.

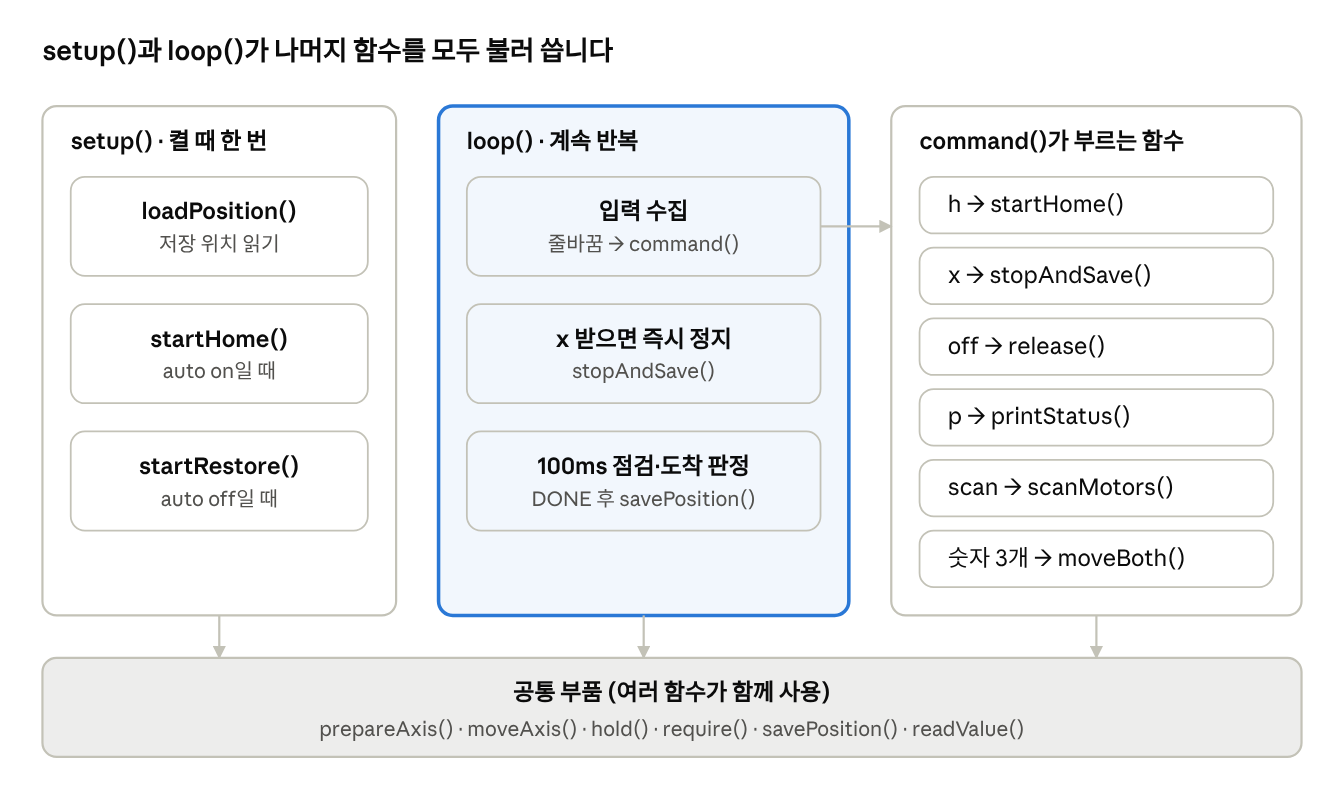
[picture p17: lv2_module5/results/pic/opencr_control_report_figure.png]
함수 호출 구조 · setup, loop, command, 공통 부품


*함수 호출 구조 · setup, loop, command, 공통 부품*

사용자 명령은 모두 `loop()` → `command()`를 거쳐 들어오고, 모터를 실제로 다루는 일은 아래의 공통 부품이 맡습니다.

## 1~40줄: 머리말과 전역 변수

파일 맨 위에는 설명 주석, 라이브러리, 그리고 모든 함수가 함께 쓰는 값들이 있습니다. `setup()`과 `loop()`가 같은 값을 써야 하므로 함수 밖(전역)에 둡니다.

### 머리말과 라이브러리 (1~13줄)

| 줄 | 코드 | 뜻 |
|---|---|---|
| 1~5 | `// ...` | 파일 설명 주석입니다. 모터 ID, 통신 속도, 명령 목록, 범위를 적어 두었습니다. |
| 6 | `#include <Dynamixel2Arduino.h>` | 다이나믹셀 모터 통신 라이브러리입니다. |
| 7 | `#include <EEPROM.h>` | 전원을 꺼도 남는 저장 공간입니다. 자동 홈 설정과 마지막 위치를 저장합니다. |
| 8~11 | `math.h`, `stdlib.h`, `string.h`, `ctype.h` | 수학 함수, 절댓값, 문자열 비교, 문자 검사에 씁니다. |
| 12 | `using namespace ControlTableItem;` | `PRESENT_POSITION` 같은 모터 항목 이름을 짧게 쓸 수 있게 합니다. |
| 13 | `Dynamixel2Arduino dxl(Serial3, 84);` | 모터 통신 객체입니다. OpenCR의 다이나믹셀 포트(`Serial3`)와 방향 제어 핀 84번을 씁니다. |

### 고정값과 상태 변수 (14~31줄)

| 줄 | 이름 | 뜻 |
|---|---|---|
| 14 | `CONTROL_BUILD_ID` | 펌웨어 버전 이름입니다. `p` 명령으로 확인합니다. |
| 15 | `ids = {12, 11}` | 모터 ID입니다. 0번이 Y축(12), 1번이 X축(11)입니다. |
| 16 | `homes = {2048, 0}` | 각 축의 홈 위치(엔코더 틱)입니다. |
| 17 | `angle_limits = {135, 180}` | 홈 기준 허용 각도입니다. |
| 18 | `targets`, `anchors` | `targets`는 현재 목표 위치, `anchors`는 홈에 해당하는 실제 틱 값입니다. 홈 기준 각도 = `targets - anchors`입니다. |
| 19 | `configured` | 축을 준비(모드 설정, 홈 기준 계산)했는지 여부입니다. |
| 20 | `active`, `sequence`, `faulted` | 이동 중인지, 순차 이동(홈·복원) 중인지, 오류로 멈춘 상태인지입니다. |
| 21~23 | `dual_move`, `dual_settled`, `dual_speeds` | 두 축 동시 이동 중인지, 각 축이 몇 번 연속 도착으로 판정됐는지, 실제 속도입니다. |
| 24 | `auto_home` | 보드 시작 시 홈 복귀 여부입니다. |
| 25 | `RETURN_SPEED_DEG_S = 30` | 홈 복귀와 위치 복원 속도(°/s)입니다. |
| 26~28 | `stage_speed`, `sequence_name`, `sequence_ticks` | 순차 이동의 속도, 이름(HOME/RESTORE), 목표 위치입니다. |
| 29 | `stage`, `settled` | 순차 이동에서 지금 움직이는 축과 연속 도착 판정 횟수입니다. |
| 30 | `stage_ms`, `poll_ms` | 이동 시작 시각과 마지막 점검 시각(밀리초)입니다. |
| 31 | `reason` | 마지막 오류 원인입니다. |

### EEPROM 저장 구조 (32~40줄)

| 줄 | 이름 | 뜻 |
|---|---|---|
| 32~33 | `BootSetting`, `BOOT_MAGIC` | 자동 홈 설정을 저장하는 묶음입니다. 주소 0에 들어갑니다. |
| 35 | `SavedPosition` | 마지막 위치 저장 묶음입니다. 확인용 번호, 두 축의 홈 기준 틱, 검사값으로 이루어져 있습니다. |
| 36~37 | `POSITION_ADDR = 16`, `POSITION_MAGIC` | 저장 주소와 확인용 번호입니다. 번호가 다르면 저장된 적이 없는 것으로 봅니다. |
| 38 | `RESTORE_TOLERANCE = 12` | 12틱(약 1.05°) 이내면 저장 위치와 같은 것으로 봅니다. |
| 39~40 | `saved_valid`, `saved_ticks` | 읽어 온 저장 위치가 있는지와 그 값입니다. |

## 42~65줄: 기본 보조 함수

다른 함수들이 공통으로 쓰는 작은 계산·읽기 함수입니다.

| 줄 | 함수 | 하는 일 |
|---|---|---|
| 43~46 | `readValue(id, item, value)` | 모터의 항목(위치, 토크 등) 하나를 읽어 `value`에 넣습니다. 통신 오류·모터 오류가 없을 때만 `true`입니다. 최대 30ms 기다립니다. |
| 48~53 | `nearestError(position, home)` | 현재 위치에서 가장 가까운 홈까지의 차이(틱)를 구합니다. 한 바퀴(4096틱) 경계를 넘는 경우도 고려해 -2048~+2048 사이로 돌려줍니다. |
| 54 | `limitTicks(i)` | 허용 각도를 틱으로 바꿉니다. X축 180° = 2048틱, Y축 135° = 1536틱입니다. |
| 55 | `ticksToDeg(ticks)` | 틱을 각도(°)로 바꿉니다. 틱 × 360 ÷ 4096입니다. |
| 56~58 | `positionCheck(s)` | 저장 위치의 검사값을 계산합니다. 저장 중 전원이 꺼져 값이 깨졌는지 알아내는 데 씁니다. |
| 60~65 | `loadPosition()` | EEPROM에서 마지막 위치를 읽습니다. 확인용 번호·검사값이 맞고 허용 범위 안일 때만 `saved_valid`를 `true`로 둡니다. |

`nearestError()`의 한계도 있습니다. 모터는 전원을 켤 때 몇 바퀴 돌았는지 기억하지 못해서, 케이블이 한 바퀴 더 감겼는지는 이 함수만으로 알 수 없습니다. 그래서 V2부터는 저장 위치를 함께 써서 판단합니다(`prepareAxis` 참고).

## 66~104줄: 안전 함수

정지, 위치 저장, 오류 처리를 담당합니다. 여러 곳에서 불리므로 한 곳에 모아 두었습니다.

### hold() (67~83줄): 그 자리에 멈추기
1. 이동 중 표시(`active`, `sequence`, `dual_move`)를 모두 끕니다.
2. 준비된 축마다 토크가 켜져 있는지 읽습니다. 못 읽으면 경고를 출력합니다.
3. 토크가 켜진 축은 현재 위치를 새 목표로 쓰고, `targets`도 그 위치로 바꿉니다.
4. 목표를 못 쓰면 토크를 끄고 “카메라를 받치라”는 경고를 출력합니다.
5. 모두 성공하면 `true`를 돌려줍니다.

### savePosition() (85~97줄): 마지막 위치 저장
1. 두 축이 모두 준비된 상태가 아니면 저장하지 않습니다.
2. 두 축의 홈 기준 위치(`targets - anchors`)와 검사값을 만듭니다.
3. 이미 저장된 값과 같으면 쓰지 않습니다. EEPROM 수명을 아끼기 위해서입니다.
4. EEPROM에 쓴 뒤 다시 읽어 똑같은지 확인합니다. 다르면 `WARNING: position save failed.`를 출력합니다.
5. 성공하면 `SAVED: X=... Y=... deg from home.`를 출력합니다.

### require() (98~104줄): 성공 여부 검사

모터 명령을 보낼 때마다 `require(명령, "원인")` 형태로 감싸서 씁니다. 명령이 실패하면 세 가지를 합니다.
- 원인을 `reason`에 저장하고 `faulted`를 `true`로 둡니다.
- `hold()`로 정지를 시도합니다.
- `FAULT: 원인`을 출력합니다.

`faulted`는 다시 `false`로 돌아가지 않습니다. FAULT 상태에서는 새 이동을 모두 거부하므로, 원인을 해결한 뒤 보드를 재시작해야 합니다.

## 106~131줄: printStatus(), 상태 출력

`p` 명령을 받으면 보드와 모터 상태를 한눈에 볼 수 있게 출력합니다. 설정을 바꾸지는 않습니다.

| 출력 줄 | 내용 |
|---|---|
| `FIRMWARE=` | 펌웨어 버전(`OPENCR_CONTROL_V2`) |
| `STATE=` | `FAULT`, `MOVING`, `IDLE` 중 하나와 오류 원인, 복귀 속도, 자동 홈 설정 |
| `SAVED_POSITION=` | 저장된 마지막 위치. 없으면 `none` |
| `tilt ID12 ...` / `pan ID11 ...` | 축별 엔코더 값(`ticks`), 홈 기준 각도(`home_deg`), 토크, 하드웨어 오류, 속도 상한 |

축 정보를 하나라도 못 읽으면 그 축은 `READ_ERROR`로 표시합니다. 축을 아직 준비하지 않았으면 `home_deg`는 가장 가까운 홈을 기준으로 계산한 값입니다.

## 132~167줄: prepareAxis(), 축 준비

모터를 움직이기 전에 항상 거치는 점검 단계입니다. 모터가 정상인지 확인하고, 홈 기준점(`anchors`)과 이동 기준점(`targets`)을 정합니다.
1. **연결·모델 확인 (135~136줄):** ping에 응답하는지, 모델이 XM430-W350인지 확인합니다.
2. **설정 점검 (137~142줄):** 토크 상태를 읽고, Homing Offset이 0인지, 하드웨어 오류가 없는지, 속도 기반 프로파일인지 확인합니다.
3. **모드 설정 (143~147줄):** 확장 위치 모드(Extended Position)가 아니면 토크를 끄고 모드를 바꿉니다. 이 모드는 여러 바퀴 회전을 셀 수 있습니다.
4. **현재 위치 읽기 (148줄)**
5. **이동 기준 결정 (150줄):** 토크를 유지 중이면 마지막 목표를 그대로 기준으로 씁니다. 그래야 여러 번 상대 이동해도 오차가 쌓이지 않습니다. 토크가 꺼져 있으면 현재 위치가 기준입니다.
6. **홈 기준점 계산 (151~160줄, 처음 준비할 때만):**
   - 현재 위치에서 가장 가까운 홈을 고릅니다.
   - 저장 위치가 있으면, 그 위치와 가장 가까운 바퀴를 고릅니다. X축이 ±180° 근처에 있을 때 어느 쪽으로 돌았는지 판단하기 위해서입니다.
   - 홈 기준 위치가 허용 범위를 벗어나면 `REJECTED`를 출력하고 멈춥니다. FAULT는 아닙니다.
7. **마무리 (161~166줄):** 통신 감시 타이머를 끄고, 가속도를 가장 완만한 값(1)으로 두고, 목표를 기준 위치로 씁니다. 그래서 토크를 켜도 모터가 튀지 않습니다.

점검 중 하나라도 실패하면 `require()`가 FAULT를 걸고 `false`를 돌려줍니다.

## 168~195줄: moveAxis()와 readyForMove()

### moveAxis(i, rel, speed) (169~189줄): 한 축만 이동

홈 복귀와 위치 복원에서 축을 하나씩 움직일 때 씁니다. `rel`은 홈 기준 목표 위치(틱), `speed`는 속도(°/s)입니다.

| 줄 | 하는 일 |
|---|---|
| 172~173 | 현재 위치와 모터에 설정된 속도 상한(Velocity Limit)을 읽습니다. |
| 174~175 | 속도를 모터 단위(1 = 1.374°/s)로 바꿉니다. 30°/s는 21(실제 약 28.9°/s)입니다. 상한을 넘으면 거부합니다. |
| 176~177 | 목표 틱 = 홈 기준점 + `rel`입니다. 모터가 표현할 수 있는 범위인지 확인합니다. |
| 178 | 이동 속도를 모터에 씁니다. |
| 179~180 | 목표를 현재 위치로 먼저 쓰고 토크를 켭니다. 토크를 켜는 순간 튀지 않게 하려는 순서입니다. |
| 181 | 통신 감시 타이머를 25(500ms)로 켭니다. 보드가 500ms 동안 모터와 통신하지 않으면 모터가 스스로 멈춥니다. |
| 182 | 실제 목표를 씁니다. 여기서 모터가 움직이기 시작합니다. |
| 183~187 | 목표와 시작 시각을 기억하고 `MOVING tilt ... deg from home at ... deg/s.`를 출력합니다. |

도착 판정은 이 함수가 아니라 `loop()`가 합니다. 그래서 함수는 명령만 보내고 바로 끝납니다.

### readyForMove() (191~195줄): 이동 가능 여부

새 이동 명령을 받기 전에 확인합니다. FAULT 상태면 `FAULT: 원인`, 이미 움직이는 중이면 `BUSY: send x to stop first.`를 출력하고 거부합니다.

## 196~231줄: 입력 해석

`5 -5 3` 같은 글자열을 숫자 세 개로 바꾸고, 쓸 수 있는 값인지 검사합니다.

### readDecimal() (197~216줄): 숫자 하나 읽기
1. 앞의 공백을 건너뜁니다.
2. `+` 또는 `-` 부호가 있으면 기억합니다.
3. 정수 부분을 한 자리씩 읽습니다. 1,000,000을 넘으면 잘못된 입력으로 봅니다.
4. `.`이 있으면 소수 부분을 읽습니다.
5. 숫자가 하나도 없거나, 숫자 뒤에 공백이 아닌 글자(예: `5a`)가 붙어 있으면 실패입니다.

`text`는 참조(`&`)로 받기 때문에, 읽은 만큼 앞으로 이동한 상태로 돌아갑니다. 그래서 연달아 부르면 다음 숫자를 읽습니다. 동적 메모리를 쓰지 않아 마이크로컨트롤러에서 안전합니다.

### parseCommonMove() (220~231줄): 이동 명령 해석

| 줄 | 하는 일 |
|---|---|
| 222~224 | `readDecimal()`을 세 번 불러 X 변화량, Y 변화량, 속도를 읽습니다. |
| 225~227 | 뒤에 다른 글자가 남아 있거나, X가 ±360°·Y가 ±270°를 넘거나, 속도가 1.374°/s 미만이면 거부합니다. |
| 228~229 | 결과를 `values`에 담습니다. 속도는 두 축에 같은 값을 넣습니다. |

여기서는 변화량만 검사합니다. 이동 후 위치가 홈 기준 범위 안인지는 현재 위치를 알아야 하므로 `moveBoth()`에서 검사합니다.

## 233~304줄: moveBoth(), 두 축 상대 이동

`5 -5 3` 명령을 실제 이동으로 바꾸는 핵심 함수입니다. 두 모터에 목표를 한 번에(Sync Write) 보내 동시에 출발시킵니다.

| 줄 | 단계 | 하는 일 |
|---|---|---|
| 236 | 이동 가능 확인 | `readyForMove()`로 FAULT·이동 중이면 거부합니다. |
| 237~238 | 순서 바꾸기 | 입력(X, Y)을 내부 순서(Y, X)로 바꿉니다. |
| 240~250 | 속도 검사 | 각 모터의 속도 상한을 읽고, 입력 속도를 모터 단위로 바꾼 뒤 상한을 넘으면 거부합니다. |
| 251~256 | 가속도 계산 | 약 0.3초 만에 설정 속도에 도달하도록 가속도를 정합니다. 모터 단위 1 = 21.4577°/s²입니다. |
| 257 | 축 준비 | `prepareAxis()`를 두 축에 부릅니다. |
| 258~271 | 목표 계산과 범위 검사 | 목표 = 현재 목표(`targets`) + 변화량입니다. 홈 기준 범위를 벗어나면 `REJECTED: X result ... outside +/-180; current ...`를 출력하고 멈춥니다. |
| 273~276 | 토크 켜기 | 두 모터의 토크와 통신 감시 타이머(500ms)를 켭니다. 목표가 아직 현재 위치라 움직이지 않습니다. |
| 277~286 | 패킷 만들기 | 모터마다 가속도·속도·목표 위치 12바이트를 묶습니다. 모터 제어표 108번 주소부터 연속으로 씁니다. |
| 287 | 동시 전송 | Sync Write 패킷 하나로 두 모터에 보냅니다. 이 순간 두 축이 함께 출발합니다. |
| 288~295 | 적용 확인 | Sync Write는 응답이 없어서, 각 모터의 목표를 다시 읽어 맞는지 확인합니다. |
| 296~303 | 상태 기록과 출력 | 두 축 이동 중으로 표시하고 `MOVING XY: dX=... dY=... -> X=... Y=... deg from home; ...`를 출력합니다. |

이 함수도 도착을 기다리지 않고 바로 끝납니다. 도착 판정과 위치 저장은 `loop()`가 합니다.

## 306~338줄: 순차 이동(홈 복귀·위치 복원)

홈 복귀와 위치 복원은 둘 다 Y축을 먼저 옮기고, 도착하면 X축을 옮깁니다. 속도는 30°/s(실제 약 28.9°/s)입니다.

| 줄 | 함수 | 하는 일 |
|---|---|---|
| 307~310 | `startSequence(name, rel)` | 이름(HOME/RESTORE)과 두 축 목표를 기억하고, Y축 이동을 시작합니다. X축은 Y축 도착 후 `loop()`가 이어서 움직입니다. |
| 312~317 | `startHome()` | `h` 명령입니다. 이동 가능 여부를 확인하고, 두 축을 준비한 뒤 목표 (0, 0)으로 순차 이동합니다. |
| 319~338 | `startRestore()` | 보드를 켤 때(`auto off`인 경우) 한 번 실행됩니다. 아래 순서를 따릅니다. |

### startRestore()의 판단 순서
1. 저장 위치가 없으면 `RESTORE: no saved position; waiting for commands.`를 출력하고 끝납니다.
2. 두 모터에 ping을 보냅니다. 응답이 없으면 `RESTORE skipped: motor ID.. no response.`를 출력하고 끝납니다. 모터 전원이 아직 없을 때 FAULT가 걸리지 않게 하려는 단계입니다.
3. 두 축을 준비합니다. 이때 저장 위치를 참고해 바퀴를 판단합니다.
4. 현재 위치와 저장 위치의 차이가 두 축 모두 12틱(약 1.05°) 이내인지 비교합니다.
5. 같으면 `POSITION OK: saved X=... Y=...`를 출력하고 그대로 둡니다. 토크도 켜지 않습니다.
6. 다르면 `POSITION CHANGED: now X=... Y=...; saved X=... Y=...`를 출력하고 저장 위치로 순차 이동합니다.

## 339~381줄: 토크 해제와 모터 조회

| 줄 | 함수 | 하는 일 |
|---|---|---|
| 340~350 | `release()` | `off` 명령입니다. 이동을 취소하고, 두 축의 토크와 통신 감시 타이머를 끕니다. 다음 이동 때 홈 기준을 다시 계산하도록 `configured`도 끕니다. 카메라 무게로 축이 내려갈 수 있으므로 먼저 받쳐야 합니다. 위치는 저장하지 않습니다. |
| 352~361 | `scanField(id, item, name)` | 모터 항목 하나를 읽어 `이름=값`으로 출력합니다. 실패하면 라이브러리 오류 번호와 모터 오류 번호를 출력합니다. |
| 363~381 | `scanMotors()` | `scan` 명령입니다. ID 11과 12에 ping을 보내고, 응답하면 모델, 펌웨어, 위치, 속도, Homing Offset, 토크, 하드웨어 오류, 입력 전압을 출력합니다. 설정은 바꾸지 않으며, 이동 중에는 거부합니다. |

`input_voltage_raw_0.1V`는 0.1V 단위입니다. 예를 들어 120이면 12.0V입니다.

## 383~419줄: 정지·저장과 명령 처리

### stopAndSave() (384~388줄)

`x`를 받으면 `hold()`로 멈추고 `STOP: holding current positions.`를 출력합니다. 정지가 성공하고 FAULT가 아니면 그 위치를 저장합니다.

### command(line) (390~419줄): 명령 분기

한 줄짜리 명령을 받아 알맞은 함수로 보냅니다. 앞뒤 공백을 지우고(391~393줄), 빈 줄이면 무시합니다(394줄).

| 줄 | 입력 | 부르는 함수 |
|---|---|---|
| 395 | `h` | `startHome()` |
| 396 | `x` | `stopAndSave()` |
| 397 | `off` | `release()` |
| 398 | `p` | `printStatus()` |
| 399 | `scan` | `scanMotors()` |
| 400~409 | `auto on` / `auto off` | 직접 처리. 설정을 EEPROM 주소 0에 쓰고 다시 읽어 확인합니다. 잘못 저장되면 `ERROR: boot setting verification failed.`입니다. |
| 410~411 | 숫자 세 개 | `parseCommonMove()`가 성공하면 `moveBoth()` |
| 412~418 | 그 밖의 입력 | 숫자로 시작하면 `INVALID XY`와 입력 바이트(16진수)를 출력합니다. 이어서 사용법을 출력합니다. |

`auto` 설정에는 확인용 번호(`BOOT_MAGIC`)와 반대 값(254/255)을 함께 저장합니다. 두 값이 모두 맞아야 켜진 것으로 봐서, 저장 공간이 깨져도 우연히 켜지지 않습니다.

## 420~438줄: setup(), 전원을 켤 때 한 번

| 줄 | 코드 | 뜻 |
|---|---|---|
| 422 | `Serial.begin(115200)` | 라즈베리파이와 USB 통신을 엽니다. main.py의 `BAUDRATE`와 같아야 합니다. |
| 423 | `dxl.begin(1000000)`, 프로토콜 2.0 | 모터와 1 Mbps로 통신을 엽니다. |
| 424~425 | `EEPROM.get(0, setting)` | 자동 홈 설정을 읽습니다. 확인용 번호와 반대 값이 맞을 때만 켭니다. |
| 426 | `loadPosition()` | 마지막 저장 위치를 읽습니다. |
| 427 | `delay(2000)` | 2초 기다립니다. 모터 전원과 USB 연결이 안정될 시간입니다. |
| 428~433 | `parseCommonMove("10 10 10", ...)` | 입력 해석 기능을 스스로 점검합니다. 실패하면 FAULT로 두고 끝납니다. |
| 434~436 | `Serial.print...` | 버전과 `OPENCR_READY` 안내를 출력합니다. |
| 437 | `if (auto_home) startHome(); else startRestore();` | `auto on`이면 홈 복귀, 아니면 저장 위치와 비교해 필요하면 복원합니다. |

`setup()`은 이동을 **시작만** 합니다. 도착까지 기다리는 일은 `loop()`가 맡아서, 복원 중에도 `x`로 바로 멈출 수 있습니다.

## 439~493줄: loop(), 계속 반복

한 번 돌 때마다 세 단계를 거칩니다. 입력 처리는 매번 하고, 모터 점검은 100ms마다 한 번만 합니다.

### 1단계: 시리얼 입력 모으기 (441~451줄)
- **441줄:** `static` 변수는 `loop()`가 끝나도 값이 유지됩니다. `line`은 최대 79글자까지 모으는 명령 상자, `used`는 모인 글자 수, `overflow`는 너무 길었는지 여부입니다.
- **442줄:** 한 번에 최대 32글자만 읽습니다. 입력이 많아도 모터 점검이 밀리지 않게 하려는 제한입니다.
- **444줄:** `x` 글자는 줄바꿈을 기다리지 않고 **받자마자** 멈춥니다. 비상 정지를 빠르게 하려는 설계입니다.
- **445~448줄:** 줄바꿈이 오면 모인 글자를 `command()`로 넘깁니다. 너무 길면 `Command too long; discarded.`입니다.
- **449줄:** 백스페이스면 한 글자를 지웁니다.
- **450줄:** 나머지 글자는 상자에 넣습니다.

### 2단계: 100ms마다 오류 점검 (452~460줄)
- **452~453줄:** 마지막 점검 후 100ms가 지나지 않았으면 여기서 끝납니다.
- **454~459줄:** 준비된 축의 하드웨어 오류를 읽습니다. 통신 실패나 오류가 있으면 FAULT입니다. 이 주기적인 통신이 모터의 통신 감시 타이머(500ms)도 매번 초기화합니다.
- **460줄:** 이동 중이 아니면 여기서 끝납니다.

### 3단계: 도착 판정

**두 축 동시 이동일 때 (461~477줄)**
- 제한 시간 = 15초 + (허용 범위의 2배 ÷ 속도)입니다. 넘으면 `dual movement timeout` FAULT입니다.
- 목표와 8틱(약 0.7°) 이내이고 거의 멈춰 있으면 “도착”으로 셈니다.
- 이 판정이 **5번 연속(약 0.5초)** 나오면 확실히 도착한 것으로 봅니다. 잠깐 지나치는 순간을 도착으로 오해하지 않기 위해서입니다.
- 두 축 모두 도착하면 `DONE XY: both axes reached; holding position.`를 출력하고 위치를 저장합니다.

**순차 이동(홈·복원)일 때 (478~492줄)**
- 제한 시간과 도착 기준은 위와 같고, 지금 움직이는 축(`stage`) 하나만 봅니다.
- 도착하면 `REACHED tilt` 또는 `REACHED pan`을 출력합니다.
- Y축(tilt)이 도착했고 순차 이동 중이면 X축 이동을 시작합니다(487줄).
- X축까지 도착하면 `DONE HOME` 또는 `DONE RESTORE`를 출력하고 위치를 저장합니다.

도착 후에도 토크는 자동으로 끄지 않습니다. 카메라가 무게로 처지지 않게 위치를 계속 잡고 있습니다.

## 출력 메시지 요약

main.py 화면에 나타나는 보드 메시지와, 그 메시지를 내는 함수입니다.

| 메시지 | 나오는 곳 | 뜻 |
|---|---|---|
| `OPENCR_READY` | `setup()` | 부팅 완료, 명령 받을 준비가 됨 |
| `POSITION OK` | `startRestore()` | 저장 위치와 같아서 움직이지 않음 |
| `POSITION CHANGED` | `startRestore()` | 저장 위치와 달라서 복원 시작 |
| `RESTORE skipped` | `startRestore()` | 모터 응답이 없어 복원을 건너뜀 |
| `MOVING XY` | `moveBoth()` | 두 축 상대 이동 시작 |
| `MOVING tilt` / `MOVING pan` | `moveAxis()` | 홈·복원 중 한 축 이동 시작 |
| `REACHED tilt` / `REACHED pan` | `loop()` | 한 축 도착 |
| `DONE XY` / `DONE HOME` / `DONE RESTORE` | `loop()` | 이동 완료, 위치 유지 |
| `SAVED` | `savePosition()` | EEPROM에 위치 저장 |
| `STOP` | `stopAndSave()` | 정지 후 위치 유지 |
| `OFF` | `release()` | 토크 해제, 카메라를 받쳐야 함 |
| `BUSY` | `readyForMove()`, `scanMotors()` | 이동 중이라 거부. 먼저 `x` |
| `REJECTED` | `moveBoth()`, `moveAxis()`, `prepareAxis()` | 범위·속도 초과로 거부. FAULT는 아님 |
| `INVALID XY` | `command()` | 숫자 명령 형식이 틀림 |
| `FAULT` | `require()` | 모터 통신·하드웨어 오류. 보드 재시작 필요 |
| `WARNING` | `hold()`, `savePosition()` | 정지 또는 저장 실패 |

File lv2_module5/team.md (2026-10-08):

# F팀 Xmen 팀 구성과 기여

> 프로젝트명: ROS-Vision-Tracker  
> 대상: [홍석민](https://github.com/hsmint) · [김혜민](https://github.com/heffeekim94-web) · [최형준](https://github.com/chj1319) · [이홍주](https://github.com/kanichong)  

## 1. 팀 구성과 역할 분담

### 1.1 책임 매트릭스

| 팀원 | GitHub 계정 | 주 역할 | 구체적인 담당 범위 | 협업 접점 |
| --- | --- | --- | --- | --- |
| [홍석민](https://github.com/hsmint) | `hsmint` | 팀장·제어·통합 | 저장소 설정, ROS–OpenCR 연동, URDF 저장소 반영·launch 연동, tracker 구조 통합, lite 제어 전환 | 팀 운영, 기능 통합, PR 병합과 공식 리뷰 |
| [김혜민](https://github.com/heffeekim94-web) | `heffeekim94-web` | 제어 | 모터 구동, 펌웨어·Python 명령, X/Y축 동시 입력·공통 속도, URDF 모델 제작, 코드·설명 자료 정리 | 인지 측 입력 형식 조정, ROS 제어 연결을 위한 초기 제어 구현 |
| [최형준](https://github.com/chj1319) | `chj1319` | ROS 통합 | 토픽·QoS, 초기 인지·제어 파이프라인, launch·검증 노드, OpenCR 시리얼·joint_states | 인지 데이터와 제어 명령 연결, 역할별 패키지·실행 구조 정리 |
| [이홍주](https://github.com/kanichong) | `kanichong` | 인지·추적 | HSV·Contour·depth·형상 검증, 실측 튜닝·평가, cube detector, CSRT·단절 복구 | 객체 검출·추적 결과를 tracker·제어 흐름과 연결 |
| 전원 | 해당 없음 | 공동 검증 | 테스트 및 검증 | 기능 간 연동과 실제 환경 동작 확인 |

---

## 2. 팀원별 상세 기여

### 2.1 [홍석민](https://github.com/hsmint)

#### 담당 역할

팀장과 제어를 맡아 저장소를 구성하고, 이후 ROS–OpenCR 연동, URDF의 저장소 반영과 시각화·launch 연동, tracker 통합, lite 제어 전환을 수행했다.

#### 주요 기여

- **팀 운영:** 초기 저장소 설정을 완료하고 각 기능의 변경을 병합했다.
- **제어 연결:** `/cmd_vel`의 `Twist`와 OpenCR 통신을 연결하고 위치 읽기를 지원했다.
- **실행·시각화 통합:** 제작된 URDF를 저장소에 반영하고 시각화·launch 구성을 추가했다.
- **구조 통합:** 인지 기능을 `xmen_tracker`로 모으고 기본 제어를 lite 경로로 전환했다.

#### 구현과 협업

| 구분 | 수행 내용 | 산출물 |
| --- | --- | --- |
| ROS와 제어 연결 | `/cmd_vel`의 `Twist`를 OpenCR에 전달하고 위치를 읽는 기능을 구현했다 | [작성 커밋 c45ef0a2](https://github.com/hsmint/ROS-Vision-Tracker/commit/c45ef0a297fd6e3609f6fd93fe2e0c8931f3e224), [PR #7](https://github.com/hsmint/ROS-Vision-Tracker/pull/7) |
| 모델 반영·실행 통합 | 제작된 URDF를 저장소에 반영하고 시각화·launch 구성을 추가했다 | [작성 커밋 acf598f5](https://github.com/hsmint/ROS-Vision-Tracker/commit/acf598f526843ed911f9f17c4beee53c6dcec0d0), [PR #8](https://github.com/hsmint/ROS-Vision-Tracker/pull/8) |
| 통합 구조 정리 | tracker 인지 기능을 `xmen_tracker`로 통합했다 | [작성 커밋 aa276ea4](https://github.com/hsmint/ROS-Vision-Tracker/commit/aa276ea49416f9fd2e690d74fac3d84b931e4169) |
| 제어 경량화와 개선 | OpenCR lite 버전을 추가하고 기본 제어를 lite로 전환했다. 모터 제한과 시간 지연 관련 코드를 수정했다 | [0c6320fd](https://github.com/hsmint/ROS-Vision-Tracker/commit/0c6320fd22a770742921ca239c1612a11d93ceef), [01051a0a](https://github.com/hsmint/ROS-Vision-Tracker/commit/01051a0a014810df25bf323d378ec02580c4827c), [c24f14dc](https://github.com/hsmint/ROS-Vision-Tracker/commit/c24f14dc1d952e9366fd40ae0a427f8fab23c1c4) |

---

### 2.2 [김혜민](https://github.com/heffeekim94-web)

#### 담당 역할

제어 영역의 모터 구동 시연과 `.ino`·`.py` 코드 작성, 팬·틸트 구조의 URDF 모델 제작을 맡았다. 초기 펌웨어를 적용하고 X/Y축 동시 명령, 속도·각도 설정을 구현하고 인지 측과 입력 형식을 조정했으며, 부팅 시 위치 복원을 조사했다.

#### 날짜별 수행 내용

| 날짜 | 작업 | 상태 | 수행 내용과 결과 | 산출물 |
| --- | --- | --- | --- | --- |
| 10월 1일 | 펌웨어 업데이트와 모터 확인 | 완료 | 펌웨어를 적용하고 라즈베리파이에서 모터 구동과 통신을 검증했다. 초기 제어 코드는 10월 2일 커밋했다 | [초기 제어 커밋](https://github.com/hsmint/ROS-Vision-Tracker/commit/c0d8332e14aa9e1327fee5df5c819834483e13eb), [PR #2](https://github.com/hsmint/ROS-Vision-Tracker/pull/2) |
| 10월 3일 | 입력값·최대값 수정, ROS 2 구독자 노드 생성 | 완료 | X/Y축 목표각을 한 입력으로 받고 두 모터에 속도를 동시에 적용했다. 이날 모터 시험에서 최대 속도 274 deg/s, 최대 각도 ±180°를 확인했다 | [동시 명령 커밋](https://github.com/hsmint/ROS-Vision-Tracker/commit/1452344a198f9f2cca26eca8b2200b50413f612f), [PR #2](https://github.com/hsmint/ROS-Vision-Tracker/pull/2) |
| 10월 6일 | 파일 가독성·이름 정리, IMU 위치값 관련 작업 | 완료 | `auto on/off` 기능을 제거하고 인지 담당 측의 입력 수정을 연계했다. 5배 가속력에 따른 반동을 분석하고 통합 측 가속력 재설정 필요성을 정리했다. URDF 모델 제작과 문제 리뷰를 완료했다 | [코드 정리 커밋](https://github.com/hsmint/ROS-Vision-Tracker/commit/9e42ad5265c0c768202276b70970d5eb8ed88cb2), [PR #3](https://github.com/hsmint/ROS-Vision-Tracker/pull/3) |

#### 문제 해결 과정

1. **설치·실행 환경 정리**
   - Arduino CLI, OpenCR 코어 1.5.3, 라이브러리와 빌드·업로더·포트 확인 절차를 정리했다.
   - SSH 대상 장치에 필요한 설치를 PC 터미널에서 실행한 문제를 파악하고 작업 환경을 구분했다.
   - 기존 `opencr_position_p.ino`를 수정하고 모터 ID를 확인했다.
2. **두 축 동시 명령 구현**
   - X/Y축 목표각과 공통 속도를 한 번에 입력하고 두 모터에 동시에 적용하도록 수정했다.
   - 10월 3일 모터 시험에서 속도·각도 범위를 확인했다. 당시 시험값은 274 deg/s와 ±180°다.
3. **부팅 시 위치 복원과 반동 분석**
   - `auto on/off` 설정, 마지막 위치 복원과 틱 단위 파라미터를 조사한 뒤 `auto on/off` 기능을 제거했다.
   - 전원 연결 시 회전 반동의 원인을 5배 가속력으로 분석하고, 통합 측에서 가속력을 재설정하도록 작업 내용을 정리했다.
   - 10월 6일 URDF 모델 제작과 제어 코드 정리를 완료했다. 부팅 반동 해소 여부는 통합 장비 시험에서 추가 검증이 필요하다.

#### 구현과 문서 정리

| 구분 | 수행 내용 | 산출물 |
| --- | --- | --- |
| 초기 제어 구현 | 카메라 제어 코드를 작성하고 진행 자료를 정리했다 | [c0d8332e](https://github.com/hsmint/ROS-Vision-Tracker/commit/c0d8332e14aa9e1327fee5df5c819834483e13eb) |
| 두 축 동시 제어 | X/Y 움직임 명령을 동시에 적용하도록 control 패키지를 수정했다 | [1452344a](https://github.com/hsmint/ROS-Vision-Tracker/commit/1452344a198f9f2cca26eca8b2200b50413f612f), [83a5479c](https://github.com/hsmint/ROS-Vision-Tracker/commit/83a5479cfb33cd3f9bcb84479e5a1bfa286c6163), [PR #2](https://github.com/hsmint/ROS-Vision-Tracker/pull/2) |
| URDF 모델 제작 | 팬·틸트 구조의 URDF 모델을 제작했다 | 10월 6일 제작 완료, [URDF 산출물](https://github.com/hsmint/ROS-Vision-Tracker/blob/8432524e0d5fd8cf6cee40536bbffdeb1c50b934/xmen_description/urdf/cctv.urdf). 저장소 반영·launch 연동은 [홍석민](https://github.com/hsmint)이 담당했다 |
| 정리와 수정 | 그림 폴더와 제어 설명 자료를 보완했다 | [9e42ad52](https://github.com/hsmint/ROS-Vision-Tracker/commit/9e42ad5265c0c768202276b70970d5eb8ed88cb2), [bcb5f547](https://github.com/hsmint/ROS-Vision-Tracker/commit/bcb5f5477ba391de62942576f13dd49c11bdbf10), [PR #3](https://github.com/hsmint/ROS-Vision-Tracker/pull/3) |

---

### 2.3 [최형준](https://github.com/chj1319)

#### 담당 역할

통합 노드와 구동 테스트를 맡아 인지·제어 작업을 지원하고 ROS 통합 구조를 설계했다. 라즈베리파이의 RealSense 입력, 토픽 주기와 QoS를 다뤘다.

#### 날짜별 수행 내용

| 날짜 | 작업 내용 | 상태 | 수행 내용과 결과 |
| --- | --- | --- | --- |
| 10월 1일 | 통합 영역의 펌웨어 업데이트 | 완료 | 통합 영역의 펌웨어 업데이트를 완료했다 |
| 10월 2일 | depth 데이터를 이용한 퍽 크기 확인, 인지 ROS 노드 구성 | 완료 | depth로 퍽 크기를 검증하고 인지 ROS 노드를 구성했다. RealSense 입력·RGBD 구독, HSV·Contour·depth 검사, `/target`, 토픽·QoS와 launch 관련 코드는 10월 3일 커밋했다 |
| 10월 6일 | 역할별 폴더 정리, 명령 토픽을 `cmd_vel`로 변경, 문서 정리 | 일지: 시작 전 / 코드: 반영 완료 | 역할별 폴더와 문서를 정리하고 명령 토픽을 `/cmd_vel`로 변경했다. PR #5를 통해 develop에 반영했다 |

#### 구현과 검증

| 구분 | 수행 내용 | 산출물 |
| --- | --- | --- |
| 인터페이스 | `/search`와 토픽·QoS의 공통 정의를 구성하고 명령 토픽을 `/cmd_vel`로 변경했다 | [a363b2af](https://github.com/hsmint/ROS-Vision-Tracker/commit/a363b2afebb6445905578969a5b843a0d3695a0a), [5cc8d389](https://github.com/hsmint/ROS-Vision-Tracker/commit/5cc8d3896097f7d317035890faaddb9df4d79e8b) |
| 초기 인지 통합 | RealSense 직접 입력·RGBD 구독, HSV·Contour·depth 검증과 `/target` 발행을 구현했다 | [14c59901](https://github.com/hsmint/ROS-Vision-Tracker/commit/14c5990117b6c1cd6a787973aba927879a4ee708) |
| 실행·검증 | 전체 실행 launch와 설정, 검증 노드·launch를 작성하고 실행·인터페이스 문서를 정리했다 | [e65647b6](https://github.com/hsmint/ROS-Vision-Tracker/commit/e65647b612cda3cb973857e3420fc56bac5510de), [ea1cd634](https://github.com/hsmint/ROS-Vision-Tracker/commit/ea1cd6342651d4d61a932452ff2424074158c657) |
| 제어·시리얼 | 팬·틸트 제어, watchdog·출력 OFF를 구현했다. OpenCR V 명령 전송·P 응답 수신, `/joint_states` 발행과 회전 제한을 추가했다 | [50c2408b](https://github.com/hsmint/ROS-Vision-Tracker/commit/50c2408b5a4e0112e23c8057f6c93771262561be), [296c9869](https://github.com/hsmint/ROS-Vision-Tracker/commit/296c9869294fd65ca2f4d2430daa7594a1f8b4fd) |
| 패키지 정리 | 인지·제어·bringup을 역할별 폴더로 옮기고 카메라 입력 방식 선택 기능을 추가했다 | [bd494262](https://github.com/hsmint/ROS-Vision-Tracker/commit/bd494262f9163058579e7ee4a2e4ee0e81135b57) |

PR #5에서 보고한 시험 결과는 다음과 같다.

- 모의 입력 시험 11/11 통과
- 모터 출력 OFF 조건에서 `/search` 시험 5/5 통과
- 실제 RPi 카메라 입력에서 `/target` 29.7 Hz, `/cmd_vel` 20 Hz 측정
- 가상 시리얼에서 명령 전송·끊김·제한 동작 검증

초기 `xmen_vision` 인지 노드와 ROS 인터페이스를 구현했다. 이후 통합 리팩터링으로 인지 코드는 `xmen_tracker`에 통합되었다.

---

### 2.4 [이홍주](https://github.com/kanichong)

#### 담당 역할

인지 영역의 카메라 입력, HSV·Contour 기반 검출, 객체 중심 계산과 미검출 처리를 맡았다. 거리·형상·깊이 검증을 구현하고, 조명 변화에 맞춰 검출 조건을 조정하며 성능을 평가했다.

#### 날짜별 수행 내용

| 날짜 | 작업 | 상태 | 수행 내용과 결과 | 산출물 |
| --- | --- | --- | --- | --- |
| 10월 1일 | 인지 예제 확인과 환경 구성 | 완료 | Raspberry Pi 펌웨어와 Ubuntu Server 24.04 이미지를 준비하고 SSH 연결·26.04 업그레이드를 진행했다. OpenCV mask·HSV·중심점 예제를 분석하고 RealSense 예제 동작을 확인했다 | 일지, [커밋 링크](https://github.com/hsmint/ROS-Vision-Tracker/commit/a251858086fe290097ee5971d8fb683cd8bdf2bf) |
| 10월 2일 | 파란 큐브 마스크·검출·추적 | 완료 | 0.1·0.2·0.5·1.0 m 거리와 가림·사라짐 조건에서 HSV·Contour 검출과 객체 중심 추적을 검토했다. 객체 사각형과 컨투어 출력을 확인했다 | 일지, [커밋 링크](https://github.com/hsmint/ROS-Vision-Tracker/commit/2a7c5d4bfe9406e9b42c6626f6055ce4570c01d2) |
| 10월 6일 | 실제 환경 HSV 튜닝과 CSRT 적용 검토 | 진행 중 | 조명·거리별 데이터로 기존 설정과 최종 설정을 비교하고 HSV 값을 수정했다. CSRT 적용을 검토했다 | 일지, [커밋 링크](https://github.com/hsmint/ROS-Vision-Tracker/commit/cc1395caa5556a392c0ec684dcdba40bddef0b77) |

#### 검출 조건과 접근 방법

10월 2일에는 다음 조건으로 검출과 추적을 검토했다.

- 실측 HSV 범위: H 104~120, S 200 이상
- 장단비, 채움비, solidity, `box_fit` 검사
- 거리 0.1~1.1 m 확인
- 실제 크기: 짧은 변 6 cm 이하, 긴 변 8 cm 이하 확인
- 가림·사라짐 조건과 객체 중심 추적 검토

10월 6일에는 어두운 배경의 옅은 파랑이 큐브 마스크에 붙으면서 크기가 과대 계산되고 `size_mismatch`로 탈락하는 문제를 분석했다. 큐브만 남도록 마스크를 조정해 평가 데이터의 검출률과 처리 시간을 개선했으며, 실측 보정을 PR #6에 반영했다. 이후 CSRT 보완과 영상 단절 복구를 구현해 PR #13에 반영했다.

#### 조건별 성능 평가

동일한 데이터에 최적화 전·최종 설정을 적용해 조건당 100장으로 평가했다. 아래는 당시 평가 결과다. 처리 시간은 해상도 맞춤부터 색·모양·깊이 검증과 중심 계산까지 측정했으며, 화면 표시와 카메라 대기 시간은 제외했다.

| 조건 | 최적화 전 검출률 | 최종 검출률 | 최적화 전 처리 ms 평균 / p95 | 최종 처리 ms 평균 / p95 |
| --- | --- | --- | --- | --- |
| 어두움, 약 0.5 m | 0% | 100% | 7.58 / 9.36 | 1.03 / 1.26 |
| 보통, 약 0.5 m | 100% | 100% | 6.07 / 6.62 | 0.96 / 1.15 |
| 밝음, 약 0.5 m | 100% | 100% | 2.84 / 3.03 | 0.97 / 1.12 |
| 0.1 m 조건, 실측 Z 0.16 m | 100% | 100% | 3.19 / 3.36 | 1.03 / 1.18 |
| 0.2 m 조건, 실측 Z 0.32 m | 100% | 100% | 6.05 / 6.52 | 1.03 / 1.17 |
| 0.5 m 조건, 실측 Z 0.55 m | 100% | 100% | 6.07 / 6.62 | 0.96 / 1.15 |
| 어두움, 1.0 m 조건, 실측 Z 1.02 m | 0% | 100% | 7.04 / 8.82 | 1.28 / 1.46 |
| 밝음, 1.0 m 조건, 실측 Z 1.02 m | 3% | 100% | 5.42 / 5.90 | 0.96 / 1.11 |

- 평가 요약 기준 평균 처리 시간을 **5.3 → 1.0 ms**로 줄였다.
- 보통 0.5 m는 조명·거리 평가에 공통으로 사용한 조건이다.
- 실제 카메라 100프레임 측정에서는 프레임 대기 26.4 ms, 검출 처리 약 1 ms를 측정했다. 위 표의 처리 시간은 검출 단계의 시간이다.
- 100% 검출률은 표에 제시한 조명·거리별 평가 데이터에서 얻은 결과다.
- 10월 6일 CSRT 적용 검토 후, 검출 실패 보완·현재 프레임 색/깊이 재검증·단절 복구를 구현했다. 최신 통합본의 재평가는 남아 있다.

#### 인지와 추적 구현

| 구분 | 수행 내용 | 산출물 |
| --- | --- | --- |
| 깊이·초점거리 | 카메라 정보와 depth·형상·HSV 설정을 보정했다 | [a2518580](https://github.com/hsmint/ROS-Vision-Tracker/commit/a251858086fe290097ee5971d8fb683cd8bdf2bf), [PR #4](https://github.com/hsmint/ROS-Vision-Tracker/pull/4) |
| 튜닝·평가 | 큐브 검출을 튜닝하고 evaluate를 추가했다. 실습실 밝기·위치·깊이를 실측해 보정했다 | [2a7c5d4b](https://github.com/hsmint/ROS-Vision-Tracker/commit/2a7c5d4bfe9406e9b42c6626f6055ce4570c01d2), [cc1395ca](https://github.com/hsmint/ROS-Vision-Tracker/commit/cc1395caa5556a392c0ec684dcdba40bddef0b77), [PR #6](https://github.com/hsmint/ROS-Vision-Tracker/pull/6) |
| detector 통합 | 실측 HSV와 실제 크기·모양 검사를 적용하고 일부 가려진 큐브를 처리하도록 detector를 구현해 tracker에 연결했다 | [64aadda4](https://github.com/hsmint/ROS-Vision-Tracker/commit/64aadda4a545a4678808d85e5b19541cda462c65), [PR #10](https://github.com/hsmint/ROS-Vision-Tracker/pull/10) |
| 처리 지연 보완 | 후보마다 전체 영상의 깊이를 계산하던 부분을 후보 주변 ROI 계산으로 개선했다 | [PR #11](https://github.com/hsmint/ROS-Vision-Tracker/pull/11) |
| CSRT와 복구 | 검출 실패 시 CSRT 보완과 현재 프레임 색·깊이 재검증을 구현했다. 같은 계열 색의 배경을 분리하고 영상 단절 후 추적 상태를 초기화하도록 수정했다 | [a1972961](https://github.com/hsmint/ROS-Vision-Tracker/commit/a1972961fb0d4359c752ec4ca66ac46a6100a55f), [PR #13](https://github.com/hsmint/ROS-Vision-Tracker/pull/13) |
| 병합 협업 | [홍석민](https://github.com/hsmint)의 ROS 제어 통합 PR #7을 병합했다 | [PR #7](https://github.com/hsmint/ROS-Vision-Tracker/pull/7) |

---

## 3. PR과 코드 산출물

### 3.1 코드 산출물

코드 산출물은 [ROS-Vision-Tracker 저장소](https://github.com/hsmint/ROS-Vision-Tracker)의 [develop 기준 커밋](https://github.com/hsmint/ROS-Vision-Tracker/commit/8432524e0d5fd8cf6cee40536bbffdeb1c50b934)에 반영되었다.

| 영역 | 주요 산출물 | 내용 |
| --- | --- | --- |
| 인지·추적 | `xmen_tracker` | 카메라 입력, HSV·Contour·깊이 검증, 큐브 추적, 목표와 제어 명령 발행 |
| 제어 | `xmen_control`, `firmware` | ROS 명령과 OpenCR 시리얼 연결, 모터 구동, 홈 복귀, 오류·timeout 처리 |
| 통합 실행 | `xmen_bringup` | 하드웨어 통합 launch, bag 입력, preview·RViz 실행 |
| 모델 | `xmen_description` | 팬·틸트 URDF와 시각화 자료. URDF 제작은 [김혜민](https://github.com/heffeekim94-web), 저장소 반영·시각화·launch 연동은 [홍석민](https://github.com/hsmint) 담당 |
| 팀 공유 자료 | 라즈베리 셋업 가이드, 인지 코드 압축파일, 조립 모델 | 라즈베리파이 환경 설정, 인지 코드와 조립 구조를 Notion 팀 페이지에 공유했다 |

### 3.2 PR 일자

| PR | 작성자 | 생성일 → 병합일 | 대상과 상태 | 실제 병합자 | 핵심 내용 |
| --- | --- | --- | --- | --- | --- |
| [#2](https://github.com/hsmint/ROS-Vision-Tracker/pull/2) | [김혜민](https://github.com/heffeekim94-web) | 2026-10-03 → 2026-10-04 | `control` → `develop`; 병합 | [홍석민](https://github.com/hsmint) | 두 축 동시 입력·공통 속도·제어 패키지 |
| [#3](https://github.com/hsmint/ROS-Vision-Tracker/pull/3) | [김혜민](https://github.com/heffeekim94-web) | 2026-10-06 → 2026-10-06 | `control` → `control`; 병합 | [홍석민](https://github.com/hsmint) | 펌웨어 정리·Python 파일명·Markdown 자료 |
| [#4](https://github.com/hsmint/ROS-Vision-Tracker/pull/4) | [이홍주](https://github.com/kanichong) | 2026-10-06 → 2026-10-06 | `vision` → `develop`; 병합 | [홍석민](https://github.com/hsmint) | depth·초점거리·HSV·형상 조건 |
| [#5](https://github.com/hsmint/ROS-Vision-Tracker/pull/5) | [최형준](https://github.com/chj1319) | 2026-10-06 → 2026-10-06 | `integration` → `develop`; 병합 | [홍석민](https://github.com/hsmint) | ROS 추적 파이프라인·역할별 패키지·검증 |
| [#6](https://github.com/hsmint/ROS-Vision-Tracker/pull/6) | [이홍주](https://github.com/kanichong) | 2026-10-06 → 2026-10-06 | `vision` → `develop`; 병합 | [홍석민](https://github.com/hsmint) | 실습실 밝기·거리·depth 실측 튜닝 |
| [#7](https://github.com/hsmint/ROS-Vision-Tracker/pull/7) | [홍석민](https://github.com/hsmint) | 2026-10-06 → 2026-10-06 | `control` → `develop`; 병합 | [이홍주](https://github.com/kanichong) | ROS–OpenCR 제어 통신·위치 읽기 |
| [#8](https://github.com/hsmint/ROS-Vision-Tracker/pull/8) | [홍석민](https://github.com/hsmint) | 2026-10-06 → 2026-10-06 | `integration` → `develop`; 병합 | [최형준](https://github.com/chj1319) | [김혜민](https://github.com/heffeekim94-web) 제작 URDF의 저장소 반영·시각화·실행 launch |
| [#10](https://github.com/hsmint/ROS-Vision-Tracker/pull/10) | [이홍주](https://github.com/kanichong) | 2026-10-07 → 2026-10-07 | `feature/tracker-detector` → `develop`; 병합 | [홍석민](https://github.com/hsmint) | cube detector를 develop에 반영 |
| [#11](https://github.com/hsmint/ROS-Vision-Tracker/pull/11) | [이홍주](https://github.com/kanichong) | 2026-10-08 → 2026-10-08 | `vision` → `develop`; 병합 | [홍석민](https://github.com/hsmint) | 인지 구조·ROI 깊이 계산·CSRT 보완 |
| [#13](https://github.com/hsmint/ROS-Vision-Tracker/pull/13) | [이홍주](https://github.com/kanichong) | 2026-10-08 → 2026-10-08 | `vision` → `develop`; 병합 | [홍석민](https://github.com/hsmint) | cube tracker·CSRT·배경 분리·단절 복구 |

### 3.3 기능별 통합 결과

`RealSense → realsense_node → tracker_node(detector + CubeTracker + P 제어) → /cmd_vel → control_lite → opencr_lite → 팬·틸트 모터`

| 영역 | 통합 결과 | 담당 기여 |
| --- | --- | --- |
| 카메라 입력 | BGR8 영상과 색상 정렬 depth를 같은 타임스탬프로 발행, CameraInfo 제공. 최신 RGB/depth 쌍만 처리 | [최형준](https://github.com/chj1319)이 초기 ROS 입력과 인터페이스를 구현했다 |
| 객체 인지 | HSV·Contour·모양·depth·실제 크기 검사. 잘린/가려진 후보와 붙은 배경 분리 | [이홍주](https://github.com/kanichong)가 튜닝·detector·추적 기능을, [최형준](https://github.com/chj1319)이 초기 인지 노드를 구현했다 |
| 시간적 추적 | SEARCH/CONFIRM/TRACK, 검출 실패 시 CSRT 보완 후 현재 프레임 색·깊이 검증 | [이홍주](https://github.com/kanichong)가 CSRT 보완과 현재 프레임 재검증을 구현하고 반영했다 |
| 목표와 명령 | `/target`의 x/y는 정규화 영상 오차, z는 면적 비율. `/cmd_vel`은 pan=`angular.z`, tilt=`angular.y`, rad/s | P 제어에 출력 제한을 적용하고, 미검출·오래된 입력에서 정지하도록 구현했다 |
| 모터 제어 | 기본 경로는 `control_lite`와 `opencr_lite.ino`. 피드백 기반 홈 복귀, 시리얼 명령/피드백 유효성 검사, timeout·fault 처리 | [김혜민](https://github.com/heffeekim94-web)이 초기 제어를 구현하고 [홍석민](https://github.com/hsmint)이 ROS 연동과 lite 전환을 수행했다 |
| 실행·시각화 | hardware launch, bag 입력 시 모터 제어 비활성화, 독립 preview·RViz 노드, URDF 모델 | [최형준](https://github.com/chj1319)이 초기 launch·검증 구성을, [김혜민](https://github.com/heffeekim94-web)이 URDF 제작을, [홍석민](https://github.com/hsmint)이 시각화·launch 연동을 담당했다 |

---

## 4. 리뷰와 협업

### 4.1 협업 방식

1. **역할 분담:** 10월 1일 회의에서 팀장·제어·통합·인지를 나누고 저장소 설정, 펌웨어, ROS 통합과 비전 최적화 작업을 배정했다.
2. **진행 상황 공유:** 타임라인과 개인 일지에 담당 작업, 문제 해결 과정과 산출물을 정리해 공유했다.
3. **인터페이스 조정:** 인지 측 입력 형식을 통일하고 제어 명령 토픽을 `/cmd_vel`로 변경했다.
4. **기능별 검증:** [이홍주](https://github.com/kanichong)가 조명·거리별 인지 성능을 평가하고 [김혜민](https://github.com/heffeekim94-web)이 모터 구동·통신과 두 축 동작을 검증했다.
5. **코드 통합:** 기능별 PR을 병합해 인지·추적·제어·실행 코드를 develop에 통합했다.

---

## 5. 프로젝트 타임라인

| 날짜 | 주요 진행 | 담당과 협업 | 관련 자료 |
| --- | --- | --- | --- |
| 10월 1일 | 역할 분담과 저장소 설정, 제어 펌웨어·모터 확인, 카메라 환경과 예제 확인 | [홍석민](https://github.com/hsmint) 팀 운영, [김혜민](https://github.com/heffeekim94-web) 제어, [최형준](https://github.com/chj1319) 통합, [이홍주](https://github.com/kanichong) 인지 | 회의·투두·개인 일지 |
| 10월 2일 | depth 기반 크기 검증·인지 ROS 노드 구성, 파란 큐브 검출·추적 검토 | [최형준](https://github.com/chj1319), [이홍주](https://github.com/kanichong) | 개인 일지 |
| 10월 3일 | X/Y축 동시 입력과 공통 속도 적용, 토픽·QoS·인지/제어·launch 기본 코드 작성 | [김혜민](https://github.com/heffeekim94-web) 제어, [최형준](https://github.com/chj1319) ROS 통합 | 개인 일지와 해당 날짜의 작성 커밋 |
| 10월 4일 | 제어 PR #2를 develop에 반영 | [김혜민](https://github.com/heffeekim94-web) 작성, [홍석민](https://github.com/hsmint) 병합 | [PR #2](https://github.com/hsmint/ROS-Vision-Tracker/pull/2) |
| 10월 6일 | 제어 정리·URDF 모델 제작 완료, 인지 튜닝, 역할별 패키지·토픽·시리얼 통합, URDF·launch 반영 | #3은 control에 병합. #4·#5·#6·#7·#8은 develop에 병합. [김혜민](https://github.com/heffeekim94-web)이 제작한 URDF를 [홍석민](https://github.com/hsmint)이 저장소·launch에 반영하고 [최형준](https://github.com/chj1319)이 #8을 병합 | 개인 일지와 병합 PR |
| 10월 7일 | cube detector 반영, tracker 구조 통합, lite 제어 전환 | [이홍주](https://github.com/kanichong) detector, [홍석민](https://github.com/hsmint) 통합·제어 변경 | [PR #10](https://github.com/hsmint/ROS-Vision-Tracker/pull/10), 직접 작성 커밋 |
| 10월 8일 | 인지·CSRT·단절 복구 변경 반영 | [이홍주](https://github.com/kanichong) 작성, [홍석민](https://github.com/hsmint) 승인·병합. PR #11에는 공동 작성 커밋 포함 | [PR #11](https://github.com/hsmint/ROS-Vision-Tracker/pull/11), [PR #13](https://github.com/hsmint/ROS-Vision-Tracker/pull/13), 10월 8일 프로젝트 타임라인 |

---

## 6. 참고 자료

- [F팀 Xmen Notion 팀 페이지](https://app.notion.com/p/teamsparta/F-_Xmen-3eb2dc3ef514801e8f3edab3247c336d)

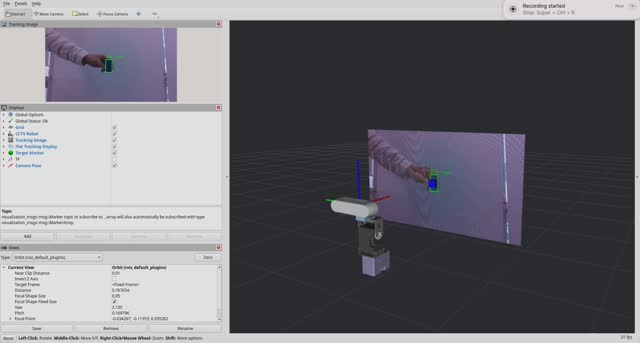
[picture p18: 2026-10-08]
video/demo2-preview.jpg

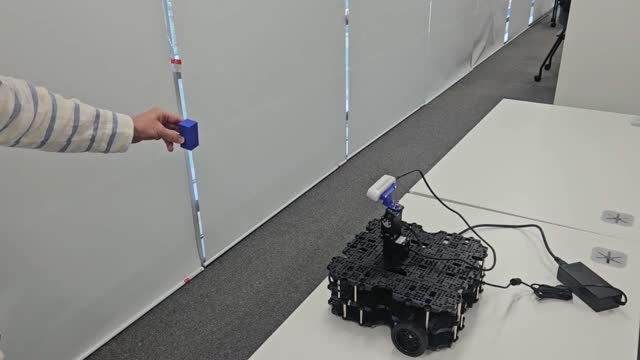
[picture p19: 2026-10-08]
video/demo-preview.jpg

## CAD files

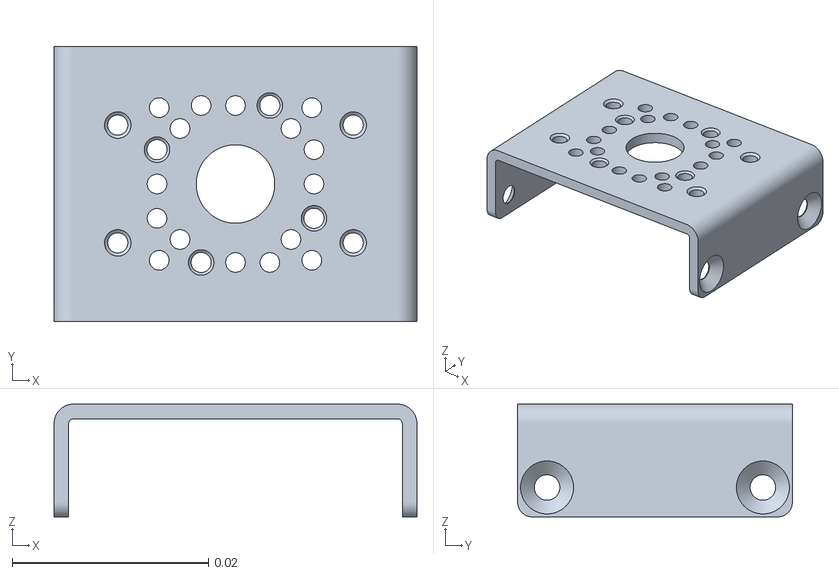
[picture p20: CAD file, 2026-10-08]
xmen_description/meshes/FR12_S102K.stl
0.037 x 0.028 x 0.0115

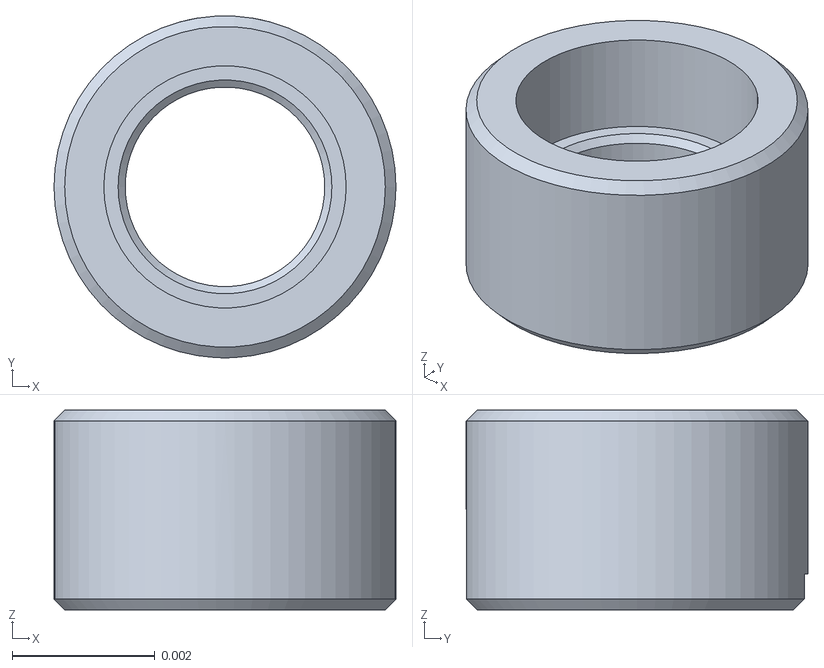
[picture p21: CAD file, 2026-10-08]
xmen_description/meshes/DYNAMIXEL_XM430_W350_R________1__DYNAMIXEL_XM430_W350_R________1_5.stl
0.0048 x 0.0048 x 0.0028

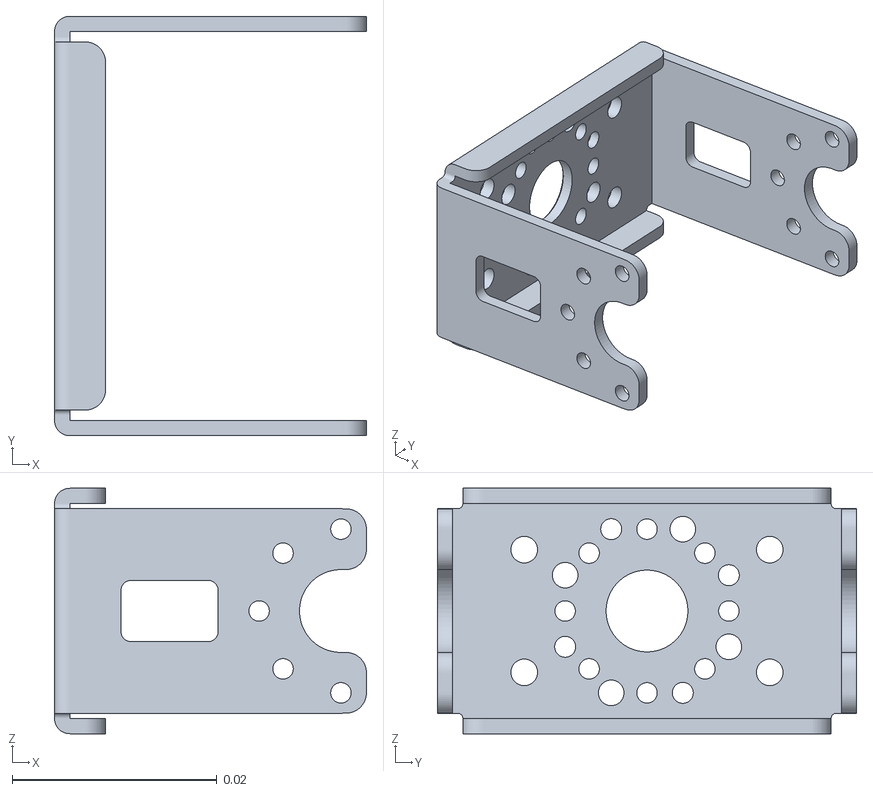
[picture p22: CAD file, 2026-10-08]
xmen_description/meshes/FR12_H101K.stl
0.0305 x 0.041 x 0.024

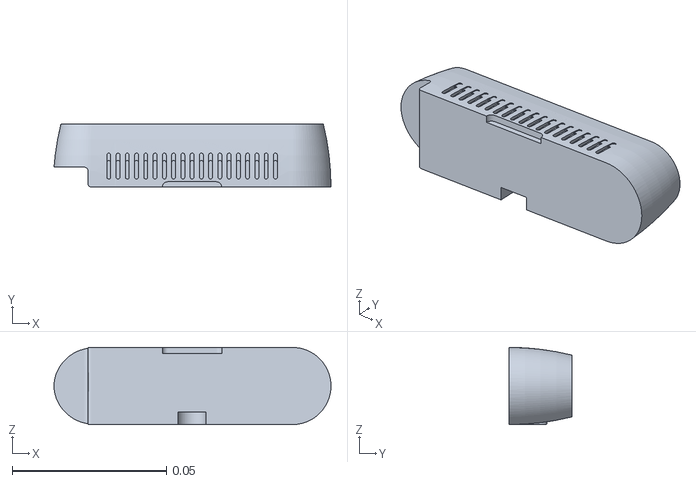
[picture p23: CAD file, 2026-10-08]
xmen_description/meshes/Part_3.stl
0.0897 x 0.0205 x 0.025

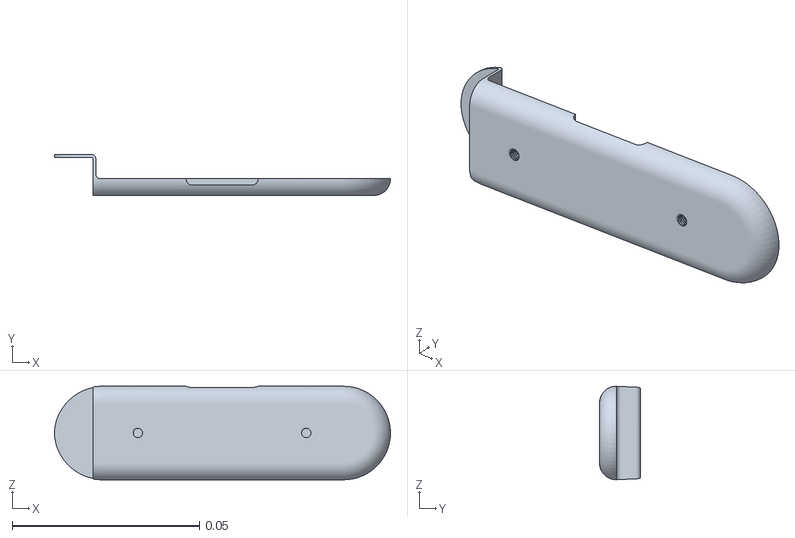
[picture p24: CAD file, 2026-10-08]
xmen_description/meshes/Part_4.stl
0.0898 x 0.011 x 0.025

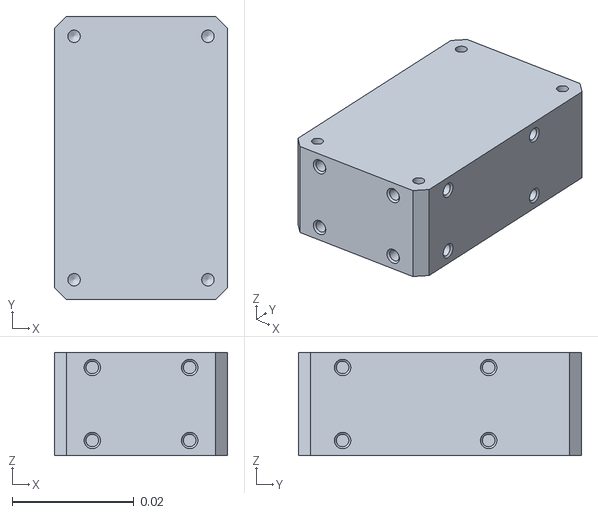
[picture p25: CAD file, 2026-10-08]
xmen_description/meshes/XM430_W350_1.stl
0.0285 x 0.0465 x 0.017

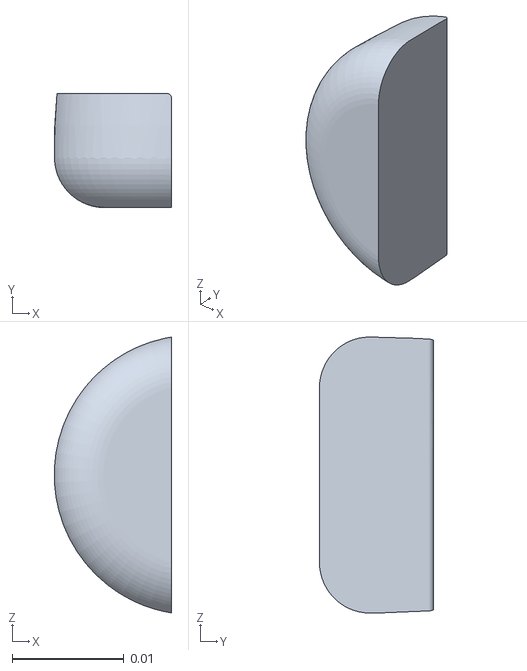
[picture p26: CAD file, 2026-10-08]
xmen_description/meshes/Part_1_1.stl
0.0105 x 0.0102 x 0.0247

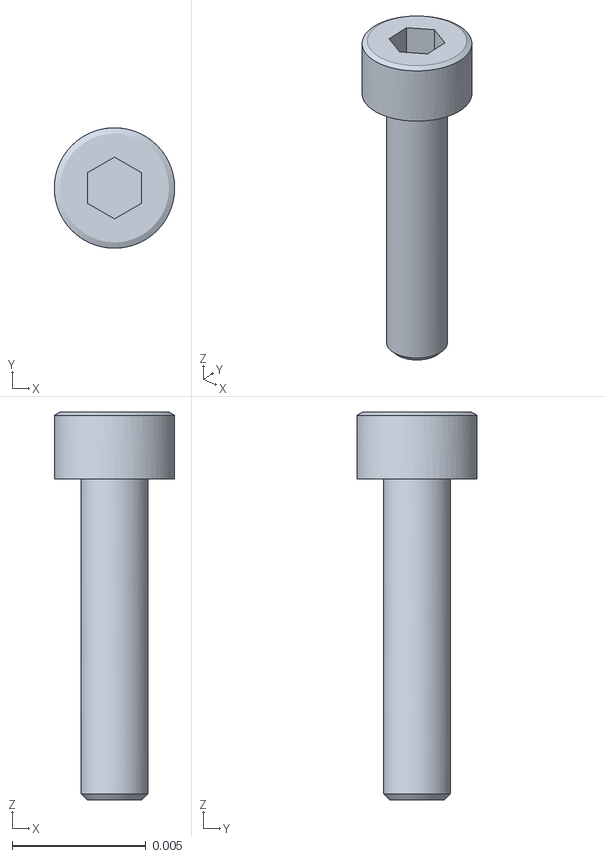
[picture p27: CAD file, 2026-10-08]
xmen_description/meshes/DYNAMIXEL_XM430_W350_R________1__DYNAMIXEL_XM430_W350_R________1_4.stl
0.0045 x 0.0045 x 0.0145

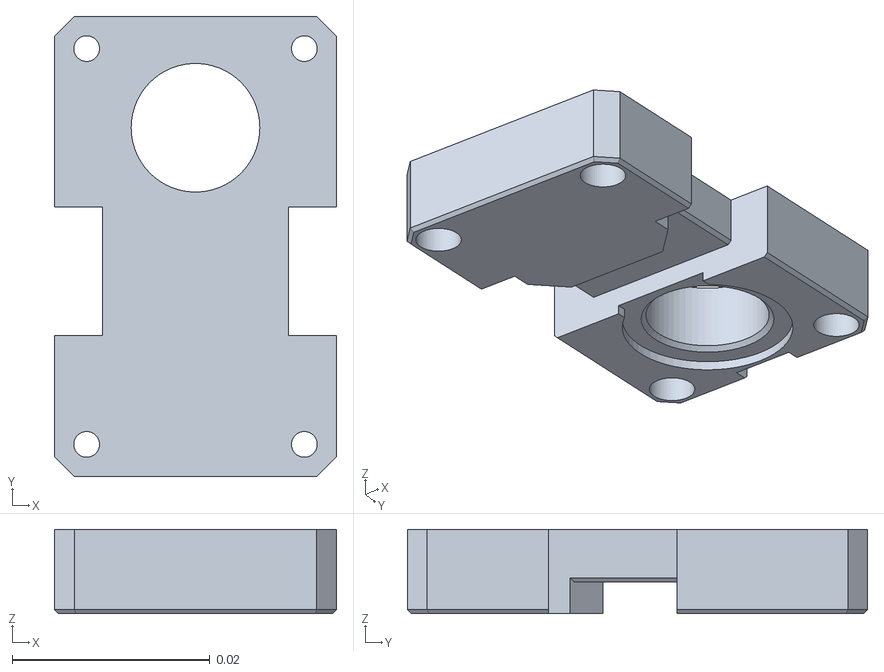
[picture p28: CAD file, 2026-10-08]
xmen_description/meshes/XM430_W350_3.stl
0.0285 x 0.0465 x 0.0085

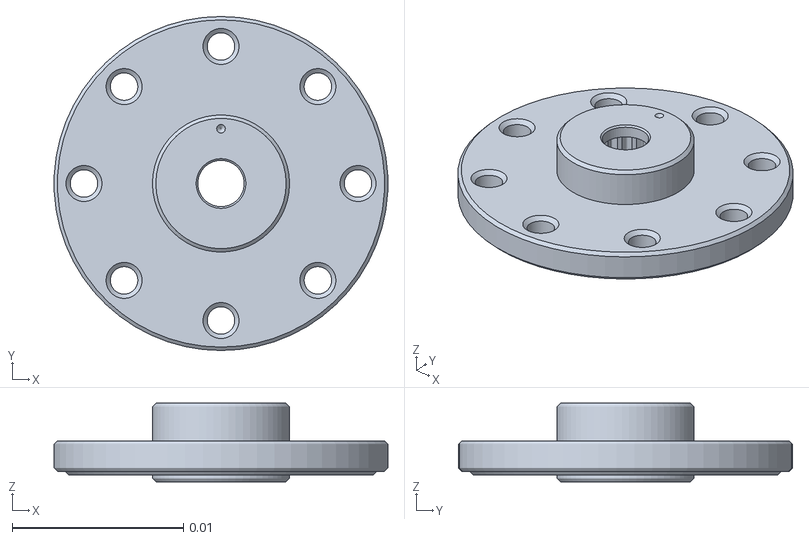
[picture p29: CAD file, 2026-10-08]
xmen_description/meshes/HN12_N101.stl
0.0195 x 0.0195 x 0.0046

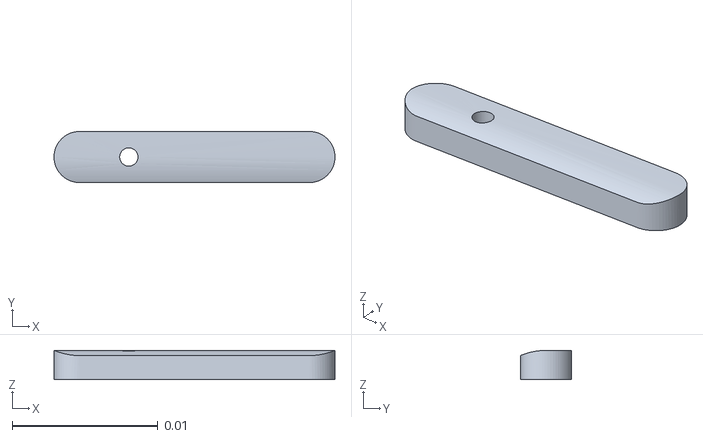
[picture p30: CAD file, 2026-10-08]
xmen_description/meshes/Part_5.stl
0.0192 x 0.0035 x 0.002

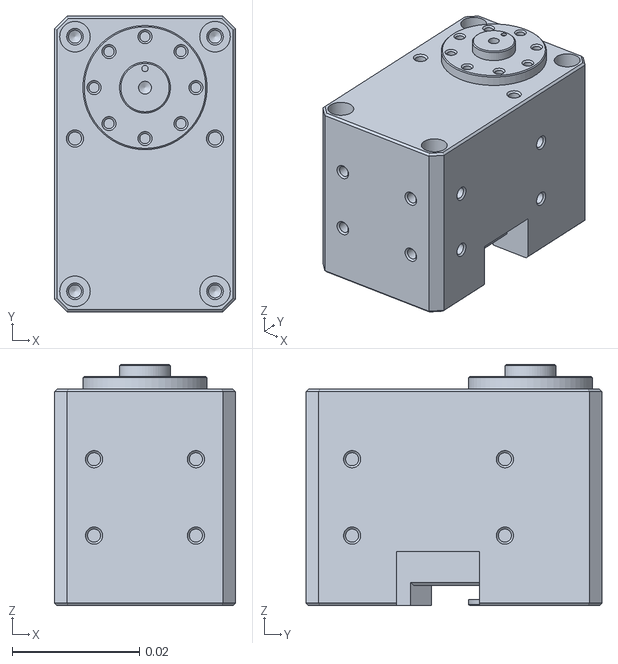
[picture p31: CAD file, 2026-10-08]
xmen_description/meshes/DYNAMIXEL_XM430_W350_R__Solid_1__DYNAMIXEL_XM430_W350_R__Solid_1.stl
0.0285 x 0.0465 x 0.0379

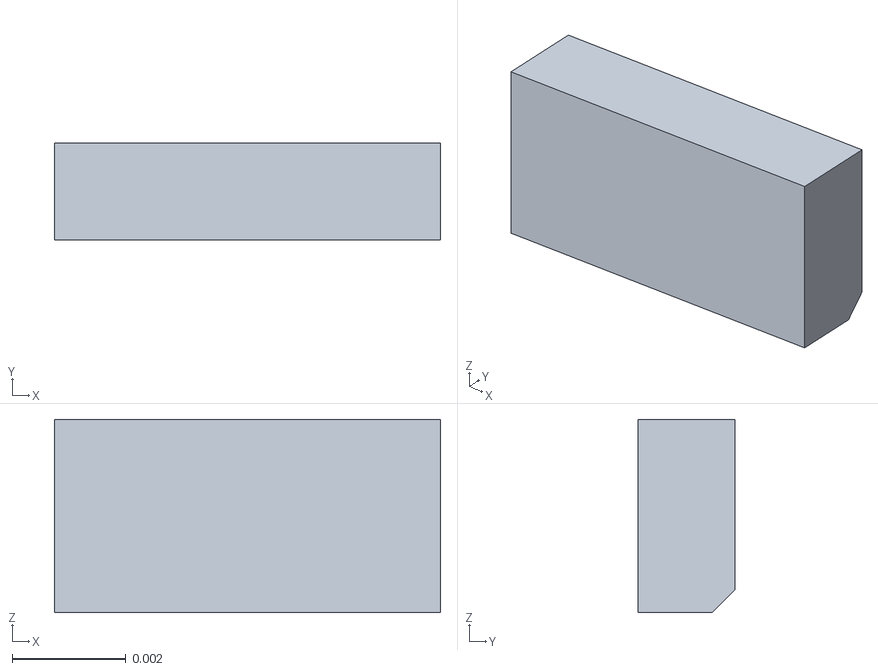
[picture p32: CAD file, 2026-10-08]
xmen_description/meshes/XM430_W350.stl
0.0068 x 0.0017 x 0.0034

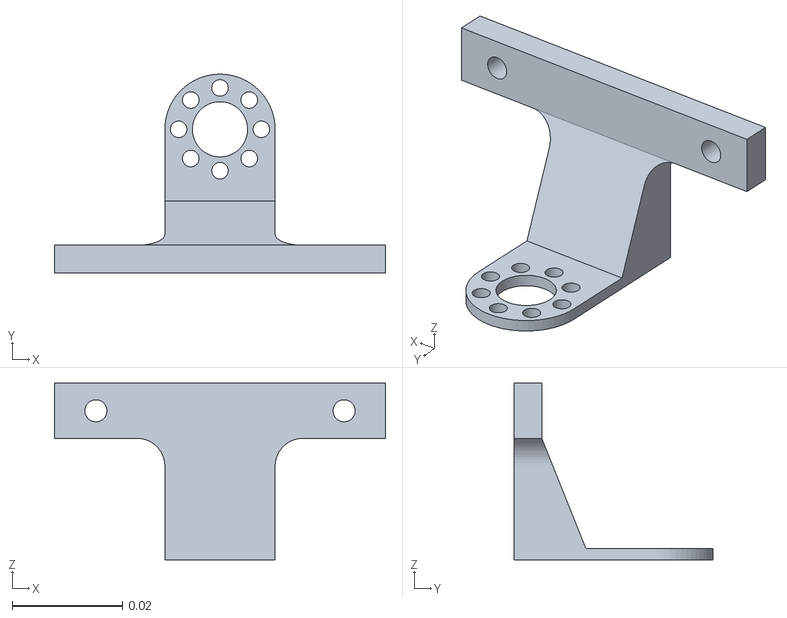
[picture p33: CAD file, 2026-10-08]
xmen_description/meshes/Part_1.stl
0.06 x 0.036 x 0.032

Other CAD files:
xmen_description/meshes/DYNAMIXEL_XM430_W350_R________1__DYNAMIXEL_XM430_W350_R________1_2.stl
xmen_description/meshes/DYNAMIXEL_XM430_W350_R________1__DYNAMIXEL_XM430_W350_R________1_3.stl
xmen_description/meshes/DYNAMIXEL_XM430_W350_R________1__DYNAMIXEL_XM430_W350_R________1_1.stl
xmen_description/meshes/DYNAMIXEL_XM430_W350_R________1__DYNAMIXEL_XM430_W350_R________1.stl
xmen_description/meshes/Part_2.stl
xmen_description/meshes/XM430_W350_2.stl

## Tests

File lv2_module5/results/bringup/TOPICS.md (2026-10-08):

# 노드 수신·송신 (토픽·액션)

Xmen 저장소의 ROS 노드(인지 `xmen_tracker`, 제어 `xmen_control`, 통합 `xmen_bringup`)가 무엇을 받고 무엇을 내는지
정리한 문서다. 토픽 이름·타입·QoS는 모두 `xmen_bringup/tracking_common/tracking_common/interface.py` 한 곳에서 정의하고, 노드는 그 값을 가져다 쓴다.
**이름·QoS를 바꿀 때는 interface.py만 고친다** — 노드 코드에 토픽 이름을 직접 쓰지 않는다.

```python
from tracking_common import interface as I
self.create_subscription(PointStamped, I.TOPICS['target']['name'], self.on_target, I.TARGET_QOS)   # 수신
self.pub = self.create_publisher(Twist, I.TOPICS['gimbal_cmd']['name'], I.CMD_QOS)                # 송신
```

---

## 1. 전체 흐름

카메라 입력은 두 방식이 있고, **RPi(보드)는 현재 방식 B**로 실행한다. detector 뒤는 두 방식이 같다.

```
방식 B (RPi, source:=ros)
[D435] ══USB══▶ realsense2_camera ──/camera/camera/rgbd──▶ target_detector ──▶ (아래와 같음)

방식 A (PC, source:=realsense, 기본)
[D435] ══USB══▶ target_detector   (pyrealsense2로 직접 연다. 영상 토픽 없음)

공통
target_detector ──/target──▶ tracking_controller ──/cmd_vel──▶ motor_driver ──X── (하드웨어 미연결)
      │                            │      ▲
      └─/perception_status         │      └── /search (액션 요청)
                                   └─/tracking_status
```

| 단계 | 노드 | 패키지 | 받는 것 → 내는 것 |
|---|---|---|---|
| 카메라 (방식 B) | `camera` (realsense2_camera) | realsense2_camera (apt) | USB → 컬러·정렬 뎁스·camera_info 묶음 |
| 인지 | `tracker_node` | xmen_tracker | 카메라 영상 → 목표의 화면 중심 오차 |
| 제어 | `tracking_controller` | target_control | 오차 → 팬·틸트 속도 명령, 추적 상태 |
| 구동 | `motor_driver` | target_control | 속도 명령 → 하드웨어 (현재 출력 OFF, 로그만) |

---

## 2. 토픽

| 토픽 | 타입 | 송신 | 수신 | QoS | 주기 |
|---|---|---|---|---|---|
| `/camera/camera/rgbd` (방식 B) | `realsense2_camera_msgs/RGBD` | realsense2_camera | target_detector (`source:=ros`), camera_viewer | 발행 reliable keep_last 1 / 구독 reliable keep_last 5 | 30 Hz |
| `/target` | `geometry_msgs/PointStamped` | target_detector | tracking_controller | best-effort, keep_last 1 | 영상마다 (약 30 Hz) |
| `/perception_status` | `std_msgs/String` | target_detector | (모니터링) | reliable, keep_last 1 | 상태 변화 시 + 1 Hz |
| `/cmd_vel` | `geometry_msgs/Twist` | tracking_controller | motor_driver | reliable, keep_last 1 | 20 Hz 고정 |
| `/tracking_status` | `std_msgs/String` | tracking_controller | (모니터링·기록) | reliable, keep_last 1 | 20 Hz |
| `/joint_states` | `sensor_msgs/JointState` | motor_driver | (모니터링·기록·RViz) | reliable, keep_last 1 | OpenCR이 각도를 보낼 때마다. 받지 못하면 발행 안 함 |

### `/target` 필드

| 필드 | 값 |
|---|---|
| `header.stamp` | 원본 영상 **촬영 시각** (RealSense global_time. 아니면 수신 시각 — detector 로그에 기준 표시) |
| `header.frame_id` | `camera_color_optical_frame` |
| `point.x` | ex = (cx − W/2)/(W/2), **오른쪽 +**, [−1, 1] |
| `point.y` | ey = (cy − H/2)/(H/2), **아래쪽 +**, [−1, 1] |
| `point.z` | 면적비 contour_area/(W×H). **0 = 미검출** — 이때 x·y는 의미 없음(0) |

- 정상 영상에서 목표가 없어도 **z=0으로 발행**한다(미검출).
- 새 영상이 없으면 **발행하지 않는다**(통신 중단). 받는 쪽은 "z=0"과 "토픽 침묵"을 구분한다.

### `/cmd_vel` 필드

| 필드 | 값 | 부호 (REP-103) |
|---|---|---|
| `angular.z` | 팬(좌우) 각속도 [rad/s] | **+ = 왼쪽**(반시계). ex>0(목표 오른쪽) → 음수 |
| `angular.y` | 틸트(상하) 각속도 [rad/s] | **+ = 아래**. ey>0(목표 아래) → 양수. *실제 모터로 부호 확인 필요* |
| 나머지 | 0 | 사용하지 않음 |

정지 명령 = 두 축 0.0을 **계속 발행**(발행을 멈추는 것이 아니다).

### 상태 값

| `/perception_status` | 뜻 |
|---|---|
| `OK` | 목표 검출 |
| `NO_TARGET` | 영상은 정상, 목표 없음 |
| `CAMERA_STALL` | 0.3 s 동안 새 영상 없음 — `/target` 발행 중단 |

| `/tracking_status` | 뜻 | 명령 |
|---|---|---|
| `WAITING` | 시작 후 아직 신선한 입력 없음 | 0, 0 |
| `TRACKING` | 검출, 한 축 이상 데드밴드 밖 | 축마다 clamp(sign × Kp × 오차) |
| `CENTERED` | 검출, 두 축 모두 데드밴드 안 | 0, 0 |
| `LOST` | 신선한 입력의 z=0 | 0, 0 (x·y 안 봄) |
| `TIMEOUT` | 마지막 신선한 입력 후 0.5 s 초과 | 0, 0 |
| `SEARCHING` | `/search` 실행 중 | 팬만 회전, 틸트 0 |

---

## 3. 액션

| 이름 | 타입 | 서버 | 클라이언트 |
|---|---|---|---|
| `/search` | `tracking_interfaces/action/Search` | tracking_controller | search_test(시험) / 상위 임무 노드 |

| 구분 | 필드 |
|---|---|
| 요청 | `direction` (+1 왼쪽 / −1 오른쪽), `speed` [rad/s] > 0, `timeout` [s] > 0 |
| 결과 | `found`, `reason` (`FOUND` \| `TIMEOUT` \| `CANCELED` \| `NO_INPUT` \| `INVALID_GOAL`), `elapsed` [s] |
| 진행 | `elapsed`, `angular_z`, `state` (`SEARCHING`) |

---

## 4. 노드별 수신·송신

### realsense_node (`xmen_tracker`)

Publishes `/camera/color/image_raw` (`bgr8`) and
`/camera/aligned_depth_to_color/image_raw` (`32FC1`, meters) with matching timestamps
and optical frames, and `/camera/color/camera_info` once at startup (transient local).
Run `ros2 run xmen_tracker realsense_node`.

### tracker_node (`xmen_tracker`)

Consumes exact-time color/depth pairs and optional camera calibration (`detector_config`,
default `xmen_tracker/config/detector.yaml`). Runs the
merged HSV/shape/depth/physical-size/occlusion pipeline and publishes `/target`,
`/perception_status`, `/tracking/bbox`, and `/cmd_vel`. Missing or stale targets
stop motion. Run `ros2 run xmen_tracker tracker_node`. Configuration and current
interfaces are documented in [xmen_tracker](../xmen_tracker/README.md).
The standalone perception node is retired. The controller descriptions below
are legacy; do not run another `/cmd_vel` source with `tracker_node`.

### tracking_controller (xmen_control/target_control/target_control/controller_node.py)

| 구분 | 내용 |
|---|---|
| 수신 | `/target` |
| 송신 | `/cmd_vel`, `/tracking_status`, `/search` 서버 |
| 동작 | `/target` 수신 시 신선도만 판정해 저장 → **20 Hz 타이머**가 상태 결정·명령 계산·발행(입력 주기와 무관하게 일정 주기) |
| 거르는 것 | NaN·범위 밖 값(`invalid`), 같은·이전 stamp(`old_or_duplicate_stamp`), 촬영 시각이 0.5 s보다 오래됨(`too_old`) |
| 정지 판단 | z=0 첫 프레임부터 `LOST`(0), 마지막 신선한 입력 후 0.5 s → `TIMEOUT`(0) |
| 파라미터 | `xmen_bringup/target_bringup/config/tracking.yaml` — kp·cmd_sign·deadband·max_speed (팬), *_tilt (틸트), rate_hz, timeout, max_input_age, tilt_enabled |

### motor_driver (xmen_control/target_control/target_control/motor_driver_node.py)

| 구분 | 내용 |
|---|---|
| 수신 | `/cmd_vel` |
| 송신 | `/joint_states` (현재 각도), OpenCR 시리얼(`port` /dev/ttyACM0, 115200) — 시리얼은 `output_enabled: true`일 때만, 기본 false면 보낼 값만 로그 |
| 동작 | 축별 상한(`hw_max_speed`, `hw_max_speed_tilt`)으로 다시 제한 → 각속도를 °/s로 바꿔 그대로 전송(적분·변환 없음) |
| 시리얼 형식 | `"V <팬> <틸트>\n"` — 팬·틸트 각속도 [deg/s] = `angular.z`·`angular.y` [rad/s] × 57.3 × 부호(`sign_pan`, `sign_tilt`). 명령마다(20 Hz) 한 줄. 형식은 제어 담당 펌웨어와 맞춘다 |
| 정지 판단 | 0.2 s 명령 없음 → `V 0.00 0.00`을 20 Hz로 계속 전송 (`명령 끊김(watchdog)`). 노드 종료 시에도 0 전송 |
| OpenCR 수신 | `"P <팬> <틸트>\n"` 현재 각도 [deg, 원점 기준] → × 부호로 `/cmd_vel` 기준(팬 + 왼쪽, 틸트 + 아래) → `/joint_states` 발행(rad, `pan_joint`·`tilt_joint`). 그 밖의 줄은 `[OpenCR] …` 로그 |
| 회전 범위 | 현재 각도가 `pan_limit_deg`·`tilt_limit_deg` 끝 이상이면 바깥 방향 속도 0(안쪽은 허용). 각도가 `position_timeout`(0.5 s) 동안 없으면 범위 확인 불가 → `require_position: true`면 두 축 0, false면 경고 후 전송 |
| 미확인 | OpenCR 펌웨어가 `P` 줄을 보내야 동작(제어 담당). 범위 값은 임시 — 실제 기구로 정하고 펌웨어와 맞춤. 실제 모터로 `sign_*` 확인 |

### 보조·검증 노드 (xmen_bringup/target_bringup, 모터 출력 OFF)

| 노드 | 수신 | 송신 | 용도 |
|---|---|---|---|
| `rviz_node` (xmen_tracker) | `/tracking/preview/compressed`, `/target` | RViz overlays | 원격 영상 확인 |
| `input_test` | `/cmd_vel`, `/tracking_status` | `/target` (모의) | 모의 입력 11단계 → PASS/FAIL, CSV |
| `gimbal_sim` | `/cmd_vel` | `/target` (모의) | 명령을 적분한 가상 짐벌로 부호 시험 |
| `search_test` | `/cmd_vel`, `/tracking_status` | `/target` (모의), `/search` 요청 | 액션 5가지 경우 |
| `interface_check` | 위 토픽 5개 전부 | 없음 | 타입·QoS·주기·호환성 검사 + 기록 |

주의: 시험 노드는 `/target`을 **모의로 발행**한다. detector와 동시에 띄우면 값이 섞인다 —
같이 켜야 하면 `export ROS_DOMAIN_ID=<다른 번호>`로 분리한다.

---

## 5. 정지 규칙 (세 겹)

| 끊기는 곳 | 감지 | 결과 |
|---|---|---|
| 카메라 → detector | detector: 0.3 s 새 영상 없음 (B: RGBD 수신 없음, A: 프레임 없음) | `CAMERA_STALL`, `/target` 발행 중단 |
| detector → controller | controller: 0.5 s 신선한 입력 없음 | `TIMEOUT`, 두 축 0을 계속 발행 |
| controller → motor_driver | motor_driver: 0.2 s 명령 없음 | 두 축 0 |
| RPi → OpenCR | OpenCR 펌웨어 워치독 | **미구현** — 제어 프로그램이 죽어도 모터가 서야 한다(발제 필수) |

---

## 6. QoS를 이렇게 정한 이유

| QoS | 토픽 | 이유 |
|---|---|---|
| best-effort, keep_last 1 | `/target` | 최신 값만 의미가 있다. 늦은 재전송보다 다음 프레임이 낫다 |
| reliable, keep_last 1 | 상태·명령 | 유실되면 안 되는 값. 최신 1개만 |
| reliable, keep_last 5 | 영상(`/camera/camera/rgbd`) 구독 | 큰 영상(≈1 MB)을 best-effort로 받으면 조각 유실로 대부분 버려졌다(163장 중 7장, PC 실측) |

reliable로 구독하는 노드는 best-effort로 발행되는 `/target`을 받지 못한다 — `/target` 구독은 반드시 best-effort.
확인: `ros2 topic echo /target --qos-reliability best_effort`

---

## 7. 확인 명령

```bash
ros2 topic list
ros2 node info /target_detector                           # 노드가 받는·내는 토픽
ros2 topic info -v /target                                # 발행·구독 노드와 QoS
ros2 topic hz /camera/camera/rgbd                         # 방식 B, 약 30 Hz
ros2 topic hz /target --qos-reliability best_effort       # 약 30 Hz (RPi 29.7)
ros2 topic hz /cmd_vel                             # 20 Hz (RPi 20.0)
ros2 topic echo /target --qos-reliability best_effort
ros2 topic echo /cmd_vel
ros2 topic echo /tracking_status
ros2 topic echo /perception_status
ros2 action send_goal /search tracking_interfaces/action/Search "{direction: 1.0, speed: 0.2, timeout: 3.0}" --feedback
```

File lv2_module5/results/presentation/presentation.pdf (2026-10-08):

# Xmen 추적 카메라

ROS 2 기반 2축 비전 추적 시스템

목차

순서 | 주제
1부 | 문제 정의와 시스템 구성
2부 | 인지와 제어
3부 | 결과와 배운 점

# 1부. 문제 정의와 시스템 구성

## 파란 큐브를 스스로 따라보는 CCTV형 2축 카메라

과제 정의

RealSense D435가 본 파란 큐브를 화면 중앙으로 끌어오는 것이 목표
목표물은 30×30×60 mm 파란 직육면체 하나 — 거리 0.2~1.0 m에서 찾아야 한다 조명은 어두움 · 보통 · 밝음 세 조건 모두에서 같은 설정으로 동작해야 한다
비슷한 색의 다른 물체(의자 · 카펫 · 파란 브래킷)를 목표로 오인하면 안 된다
사람이 큐브를 들고 움직이거나 손에 반쯤 가려져도 계속 따라가야 한다

## 목표 사양

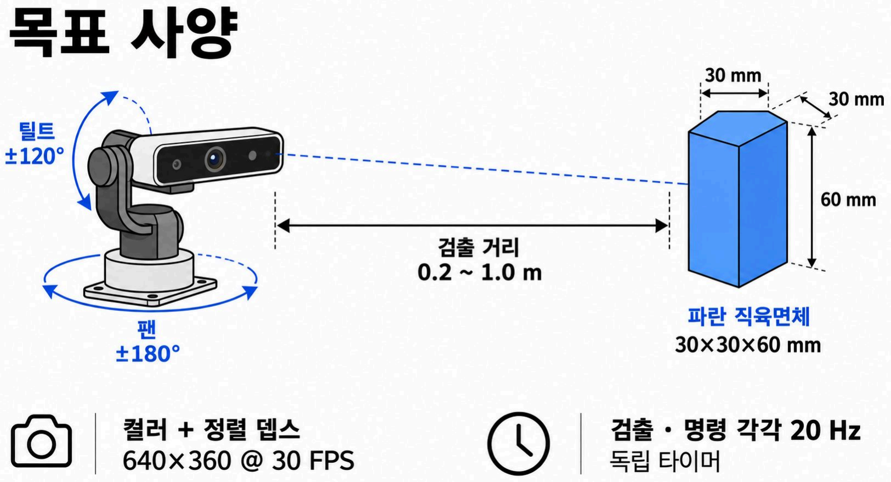
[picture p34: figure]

# | 항목 | 사양 | 비고

1 | 검출 거리 | 0.2 ~ 1.0 m | 실측 Z 2.01~1.03 m
2 | 목표물 | 30×30×60 mm | 파란 직육면체
3 | 영상 | 640×360 @ 30 FPS | 컬러 + 정렬 뎁스
4 | 검출 · 명령 주기 | 각각 20 Hz | 독립 타이머
5 | 구동 범위 | ±180° / ±40° | 팬 / 틸트

## 하드웨어 구성

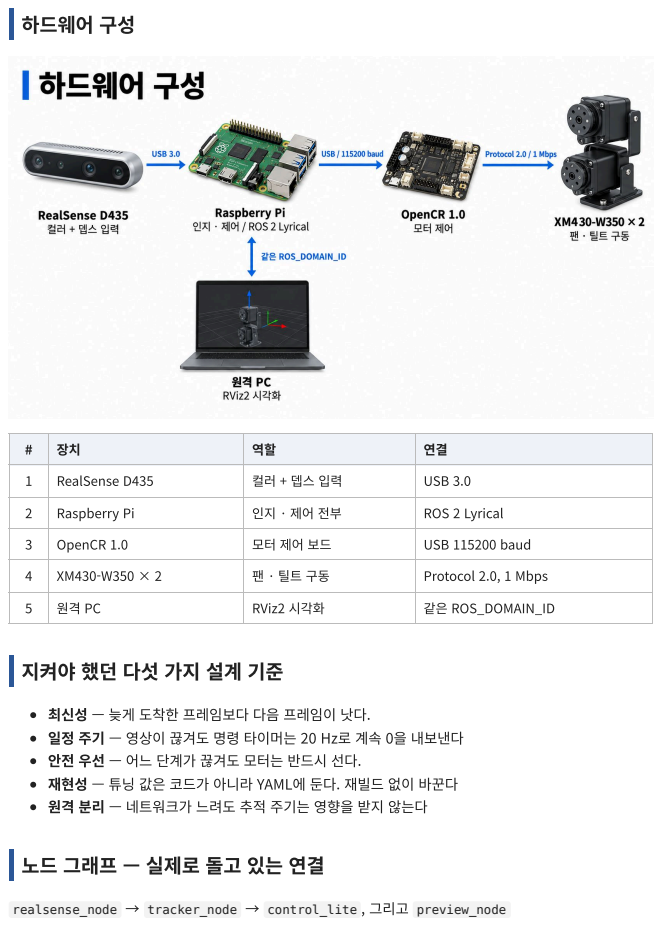
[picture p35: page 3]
realsense_node → tracker_node → control_lite , 그리고 preview_node

1 | RealSense D435 | 컬러 + 뎁스 입력 | USB 3.0

2 | Raspberry Pi | 인지 · 제어 전부 | ROS 2 Lyrical

3 | OpenCR 1.0 | 모터 제어 보드 | USB 115200 baud

4 | XM430-W350 × 2 | 팬 · 틸트 구동 | Protocol 2.0, 1 Mbps

5 | 원격 PC | RViz2 시각화 | 같은 ROS_DOMAIN_ID

지켜야 했던 다섯 가지 설계 기준

최신성 — 늦게 도착한 프레임보다 다음 프레임이 낫다.
일정 주기 — 영상이 끊겨도 명령 타이머는 20 Hz로 계속 0을 내보낸다
안전 우선 — 어느 단계가 끊겨도 모터는 반드시 선다.
재현성 — 튜닝 값은 코드가 아니라 YAML에 둔다. 재빌드 없이 바꾼다
원격 분리 — 네트워크가 느려도 추적 주기는 영향을 받지 않는다

노드 그래프 — 실제로 돌고 있는 연결

## 패키지 다섯 개, 역할 하나씩

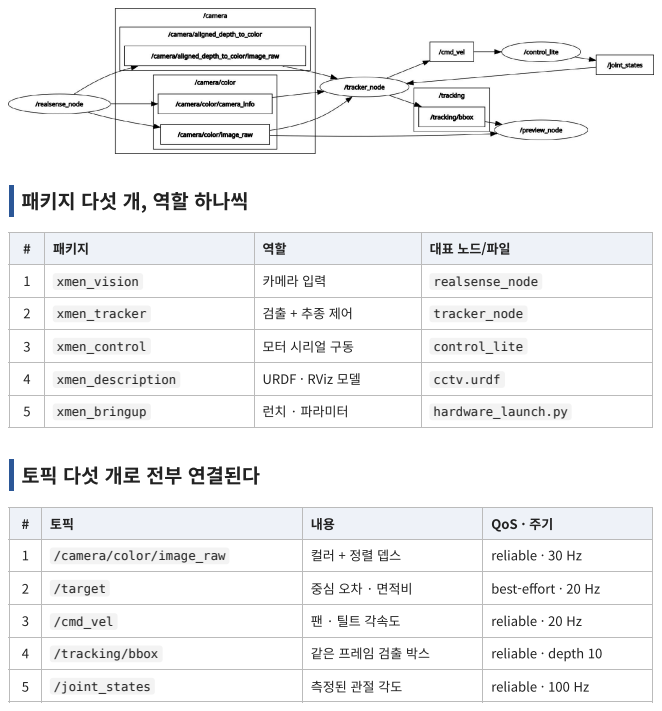
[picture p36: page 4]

# | 패키지 | 역할 | 대표 노드/파일

1 | xmen_vision | 카메라 입력 | realsense_node

2 | xmen_tracker | 검출 + 추종 제어 | tracker_node

3 | xmen_control | 모터 시리얼 구동 | control_lite

4 | xmen_description | URDF · RViz 모델 | cctv.urdf

5 | xmen_bringup | 런치 · 파라미터 | hardware_launch.py

토픽 다섯 개로 전부 연결된다

# | 토픽 | 내용 | QoS · 주기

1 | /camera/color/image_raw | 컬러 + 정렬 뎁스 | reliable · 30 Hz

2 | /target | 중심 오차 · 면적비 | best-effort · 20 Hz

3 | /cmd_vel | 팬 · 틸트 각속도 | reliable · 20 Hz

4 | /tracking/bbox | 같은 프레임 검출 박스 | reliable · depth 10

5 | /joint_states | 측정된 관절 각도 | reliable · 100 Hz

# 2부. 인지와 제어

## 검출은 다섯 단계를 순서대로 통과한다

단계 | 검사 | 기준
① | 색 마스크 | HSV + 최소 채도
② | 면적 | 픽셀 하한 · 상한
③ | 모양 | 장단비 · 채움비
④ | 상자 판정 | box_fit 다각형 근사
⑤ | 뎁스 검증 | 거리 · 실제 크기

## 뎁스로 픽셀을 센티미터로 바꾼다

뎁스 검증

컨투어 안 뎁스의 중앙값 Z를 쓴다 — 경계 화소는 1회 침식으로 제외한다
핀홀 모형: 실제 길이 = 픽셀 길이 × Z / f . 회전에 무관하게 외접사각형 변을 쓴다 기준은 짧은 변 ≤ 6 cm, 긴 변 ≤ 8 cm, 실제 넓이 3~30 cm², 거리 0.1~1.1 m 초점거리는 camera_info 가 오면 실제 값으로 바꾸고 면적 기준을 다시 계산한다 너무 가까워 뎁스가 없으면 800 px 이상일 때만 색과 크기만으로 통과시킨다

## 제어 — 오차 하나를 각속도로 바꾼다

tracker_node / 추종 제어

명령 = clamp(sign × Kp × 정규화 오차, ±max) — P 제어 하나로 끝낸다 |오차| < 데드밴드 0.05면 0 — 중앙 근처에서 좌우로 떠는 것을 막는다
팬은 angular.z , 틸트는 angular.y . 나머지 성분은 항상 0이다 REP-103을 따른다 — angular.z + = 왼쪽, angular.y + = 아래
각도가 아니라 각속도다 — 모터 드라이버가 위치로 적분하지 않는다

## control_lite — 100 Hz로 시리얼을 지킨다

xmen_control / control_lite

/cmd_vel 을 받아 'v 팬 틸트' 한 줄을 보내고, 'p' 로 현재 위치를 되묻는다

10 ms 주기 타이머가 수신 버퍼를 읽어 줄 단위로 끊고 해석한다
받은 엔코더 틱을 라디안으로 바꿔 /joint_states 에 pan · tilt로 발행한다 0.2 s 동안 새 명령이 없으면 0을 보낸다 — 지난 Twist는 절대 재사용하지 않는다 포트는 exclusive로 연다 — 다른 프로세스가 같은 포트를 잡지 못하게 한다

## 시작할 때 반드시 원점을 잡고 들어간다

control_lite / 홈 시퀀스

틸트를 먼저, 그다음 팬 — 두 축을 동시에 움직이지 않는다
4틱 이내까지 접근한 뒤, 8틱 밴드 안에서 0.2 s 머물러야 도착으로 본다 좁은 밴드로 들어가 넓은 밴드로 판정해 경계에서 떠는 것을 막는다
한 축을 맞추는 사이 다른 축이 8틱 밖으로 밀리면 최대 3번까지 다시 한다 30초 안에 못 맞추면 시작 · 최근접 위치와 마지막 명령을 남기고 멈춘다

# 3부. 결과와 배운 점

## 끊기는 지점마다 정지 규칙을 뒀다

# | 구간 | 조건 | 동작

1 | 카메라 → 검출 | 0.5 s 영상 없음 | CAMERA_STALL
2 | 검출 → 제어 | 0.5 s 입력 없음 | 두 축 0 발행
3 | 제어 → 모터 | 0.2 s 명령 없음 | 'v 0 0' 전송
4 | Pi → OpenCR | 모터 워치독 200 ms | 모터 자체 정지
5 | 노드 종료 | 종료 직전 0 발행 | shutdown 처리

## 원격 PC로 원본 영상을 보내지 않는다

preview_node

640×360 컬러 30 Hz 원본은 초당 약 21 MB — 흘리면 추적까지 같이 느려진다 Pi에서 박스를 그린 뒤 JPEG 품질 70으로 5 Hz만 내보낸다
구독자가 하나도 없으면 인코딩 자체를 하지 않는다
영상과 박스는 타임스탬프가 정확히 맞는 짝만 보낸다 — 옛 박스를 덧그리지 않는다 원본 RGB · 뎁스는 Pi 안에 남고, 검출 · 명령은 20 Hz 그대로다

## RViz2에서 로봇과 목표를 함께 본다

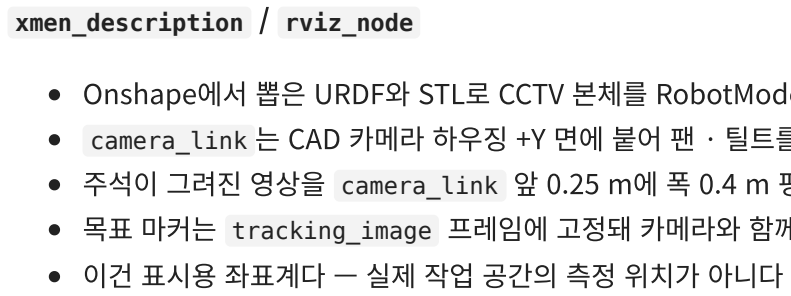
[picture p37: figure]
xmen_description / rviz_node; 이건 표시용 좌표계다 — 실제 작업 공간의 측정 위치가 아니다

Onshape에서 뽑은 URDF와 STL로 CCTV 본체를 RobotModel로 띄운다 camera_link 는 CAD 카메라 하우징 +Y 면에 붙어 팬 · 틸트를 따라 움직인다 주석이 그려진 영상을 camera_link 앞 0.25 m에 폭 0.4 m 평면으로 세운다 목표 마커는 tracking_image 프레임에 고정돼 카메라와 함께 돈다

## 튜닝과 평가를 명령 하나로 돌린다

target_perception / tuning · evaluate

tune — 화면에서 드래그하면 그 화소로 HSV 범위를 제안하고 트랙바로 다듬는다 collect — 조명 · 거리 라벨을 붙여 컬러 + 뎁스를 30장씩 데이터셋으로 모은다 bench — 조건별 100프레임의 검출률 · Z · 처리 시간을 측정한다 evaluate — 저장된 뎁스로 노드와 같은 검증까지 돌려 설정 A · B를 비교한다 결과는 조명×거리 인식률 표와 조건별 몽타주 이미지로 남는다

정리

색으로 찾고, 뎁스로 확인하고, 오차 하나로 움직인다

끊길 수 있는 모든 지점에 정지 규칙을 걸었다

ROS 2 Lyrical · RealSense D435 · OpenCR · XM430-W350 × 2

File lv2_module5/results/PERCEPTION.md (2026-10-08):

# Perception tuning and evaluation

목표: 파란 30×30×60 mm 직육면체, 어두움~밝음, 0.1~1 m. D435 컬러·뎁스 640×360.

| 파일 | 내용 |
|---|---|
| `xmen_tracker/detector.py` | 검출: HSV(엄격 범위) → 컨투어 → 면적·모양 → 뎁스 거리·실제 크기 → 선택 → 볼록껍질 중심 |
| `xmen_tracker/cube_tracker.py` | 같은 큐브 유지 + 검출이 놓친 프레임만 CSRT로 이어 현재 프레임에서 확인, 균일성 검사(청바지 차단) |
| `xmen_tracker/tracker_node.py` | 동기화 영상 검출·추적 및 팬/틸트 제어 |
| `tools/csrt_track.py` | 추적 시험: 모의 가림·방해물 비교, `--camera --record`(n 키 = 큐브 없음 표시), `--replay` |
| `xmen_tracker/tuning.py` | `tuning` — HSV 튜닝, 장면 기록, 조건별 검출률 측정, 평가 데이터 수집 |
| `xmen_tracker/evaluate.py` | `evaluate` — 조명×거리 인식률 평가, 설정 비교 |
| `config/detector.yaml` | 검출 설정(노드·도구 공용) |
| `data/` | `evaluate --sim` 기준 실제 영상(큐브 있음·없음) |

## 노드 실행
```bash
ros2 run xmen_tracker realsense_node
# In another terminal:
ros2 launch xmen_tracker perception.launch.py
```

## 튜닝·평가 도구
카메라는 한 프로세스만 연다 — **realsense_node를 끄고** 실행한다.
기본 설정은 패키지 `config/detector.yaml`(`--symlink-install`이면 저장소 파일을 바로 고친다),
결과는 `<현재 작업 폴더>/results/perception/`.

```bash
ros2 run xmen_tracker tuning tune --camera       # 드래그→HSV 제안, 트랙바, f=노출 고정, w=설정 기록
ros2 run xmen_tracker tuning live --camera       # 실시간 확인, s=증거 저장
ros2 run xmen_tracker tuning scenes --camera     # 보임 → 없음 → 가림, TP/TN 판정
ros2 run xmen_tracker tuning bench --camera --label dark_1.0m        # 조건별 100프레임 검출률·Z·처리 시간
ros2 run xmen_tracker tuning collect --camera --label dark_1.0m --light dark --distance 1.0
ros2 run xmen_tracker tuning collect --camera --label dark_empty --light dark --absent   # 오검출 측정용
ros2 run xmen_tracker evaluate --dataset ~/ws/results/perception/dataset --config A.yaml B.yaml
ros2 run xmen_tracker evaluate --sim --ablation  # 실제 영상 1장 변형(모의) — 빠른 비교용
```

- `collect`는 큐브를 **받침대에 고정**하고, 정지 화면에서 큐브를 드래그한 뒤 Enter → 30장(컬러 + 뎁스) 저장.
- `evaluate`는 저장된 뎁스로 노드와 같은 검증(거리·실제 크기·겹침 분리)까지 한다. `--no-depth`는 색·모양만.
- 결과: `eval/eval_dataset.md`(조명×거리 인식률·오검출률·중심 오차), `eval/montage_*.png`(조건별 검출 화면).

권장 조건: 조명 {어두움, 보통, 밝음} × 거리 {0.1, 0.2, 0.5, 1.0 m} + 조명마다 큐브 없는 장면.

## 결과를 보고 고칠 곳 (`config/detector.yaml`)

| 증상 | 확인 | 고칠 값 |
|---|---|---|
| 어두울 때 놓침 | mask에 큐브가 안 나옴 | `hsv_ranges` V 하한, `min_chroma`, 또는 조명 |
| 밝을 때 큐브가 조각남 | 하이라이트가 mask에서 빠짐 | `hsv_ranges` S 하한, `relaxed_ranges` S 하한 |
| 1 m에서 놓침 | 탈락 `too_small` | `depth.min_area_px`, `selection.min_area_factor` |
| 0.1~0.2 m에서 놓침 | 탈락 `no_depth`·`size_mismatch` | `depth.no_depth_min_area`, `depth.max_short_m`·`max_long_m` |
| 다른 파란 물체 오검출 | 목표 없는 장면의 검출 | `hsv_ranges` S 하한↑, `min_extent`·`min_solidity` 엄격히, 무늬 있는 천(청바지)은 `tracking.min_fill`·`min_v` |
| 가려질 때 놓침 | `csrt_track.py --replay`에서 미검출 구간 | `tracking.verify_area`↓, `hold_frames`↑ |
| 청바지 등 파란 천 앞에 든 큐브를 놓침 | 탈락 `size_mismatch`·`low_extent`(큐브+천이 한 덩어리) | `selection.color_split`(`lower` S·V 하한) |
| 추적 중 다른 물체로 옮겨 감 | 기록 영상에서 상자가 다른 물체로 이동 | `tracking.z_gate`↓, `assoc_dist`↓ |
| 사각 면이 아닌 파란 물체(원·타원·고리) 오검출 | 탈락 사유에 `not_box`가 없음 | `selection.box_fit` (`base`, `pixel` 낮추면 엄격, `min_px` 낮추면 먼 거리까지 검사) |
| 비스듬한·모서리 방향 큐브를 놓침 | 탈락 `not_box`·`size_mismatch` | `box_fit.base`·`pixel`↑, `depth.max_short_m`(이론 최대 5.4 cm) |
| 화면 가장자리·손에 가려 일부만 보일 때 놓침 | 탈락 `bad_aspect`·`low_extent`·`size_mismatch` | `selection.partial` (`max_aspect`, `front_margin_*`, `front_ratio`, `ring_front_ratio`, `min_area_m2`) |

사각 면으로 된 상자인지(`selection.box_fit`): 상자 실루엣은 어느 방향에서도 꼭짓점 4~6개 볼록 다각형이다.
볼록껍질을 6각형 이하로 근사했을 때의 평균 틈(넓이 차 ÷ 둘레 ÷ √넓이)이 크면 곡선 테두리(원·타원·고리)로 보고 `not_box`.
실루엣이 `min_px`(500 px, 약 0.7 m)보다 작으면 해상도가 부족해 검사하지 않는다. 반원처럼 직선 변이 있는 곡선 물체는 통과한다.

일부만 보이는 큐브(`selection.partial`): 모양·넓이 하한에 걸려도 **화면 가장자리에 잘렸거나**(border)
**뎁스로 본 오목부·둘레가 큐브보다 가까울 때**(손가락 등 앞 물체, occluded)만 기준을 완화한다. 크기 상한은 그대로.
홈·구멍이 있는 다른 물체는 오목부로 뒤쪽 배경이 보여 완화되지 않는다. 검출 화면 둘째 줄에 `PARTIAL(border|occluded)`, 기록 JSON에 `partial`.

설정을 고친 뒤 노드만 다시 켜면 적용된다(재빌드 불필요).

tracker_node와 도구는 같은 검증을 쓴다: 뎁스가 없으면(D435 최소 측정거리 안쪽) `depth.no_depth_min_area` 이상일 때만 색·모양으로 통과.

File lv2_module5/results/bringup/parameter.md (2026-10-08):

# param — 설정 파일 설명

`hardware_launch.py`가 읽는 설정 파일 네 개를 정리한다. 튜닝 값은 코드가 아니라 이 YAML에 두므로, 재빌드 없이 파일만 바꿔서 조정한다.

| 파일 | 읽는 쪽 | 런치 인자 | 내용 |
| --- | --- | --- | --- |
| [`tracker.yaml`](tracker.yaml) | `tracker_node` | `params_file` | 추종 제어 게인 · 주기 · 타임아웃 |
| [`detector.yaml`](detector.yaml) | `tracker_node` (`detector_config`) | `detector_config` | 큐브 검출(HSV · 크기 · 모양 · 뎁스) |
| [`control.yaml`](control.yaml) | `control_lite` | `control_params_file` | 모터 구동 노드 설정 |
| [`bag_qos.yaml`](bag_qos.yaml) | `ros2 bag play` | (`bag_path`를 줄 때 자동 적용) | 재생할 영상 토픽의 QoS |

다른 파일을 쓰려면 런치 인자로 경로를 넘긴다.

```bash
ros2 launch xmen_bringup hardware_launch.py detector_config:=/path/to/my_detector.yaml
```

---

## tracker.yaml

`tracker_node`의 ROS 파라미터. 화면 중심 오차(ex, ey ∈ [-1, 1])를 팬 · 틸트 각속도(`/cmd_vel`)로 바꾼다.
명령 = `clamp(sign × kp × 오차, ±max_speed)`, |오차| < `deadband`면 0.

### 팬(좌우, `angular.z`)

| 파라미터 | 값 | 단위 | 의미 |
| --- | --- | --- | --- |
| `kp` | 1.5 | (rad/s) / 정규화 오차 | 비례 게인. ex = 0.4 → 0.6 rad/s |
| `cmd_sign` | -1.0 | — | 명령 부호. REP-103에서 `angular.z` + = 왼쪽이므로, 목표가 오른쪽(ex > 0)이면 음수 명령 |
| `deadband` | 0.05 | 정규화 오차 | \|ex\| < 0.05면 정지 — 중심 근처 떨림 방지 |
| `max_speed` | 0.9 | rad/s | 명령 상한(포화) |

### 틸트(상하, `angular.y`)

| 파라미터 | 값 | 단위 | 의미 |
| --- | --- | --- | --- |
| `tilt_enabled` | true | — | false면 팬 1축만 제어 |
| `kp_tilt` | 1.2 | (rad/s) / 정규화 오차 | 세로 화각이 좁아(ey = 1 ≈ 21°, 팬 ex = 1 ≈ 35°) 팬보다 작게 |
| `cmd_sign_tilt` | 1.0 | — | REP-103에서 `angular.y` + = 아래. 목표가 아래(ey > 0)면 양수 명령 |
| `deadband_tilt` | 0.05 | 정규화 오차 | \|ey\| < 0.05면 정지 |
| `max_speed_tilt` | 0.6 | rad/s | 중력이 걸리는 축이라 팬보다 낮게 |

### 주기 · 타임아웃

| 파라미터 | 값 | 단위 | 의미 |
| --- | --- | --- | --- |
| `tracking_hz` | 20.0 | Hz | 검출 주기. 가장 최근의 동기화된 RGB · 뎁스 쌍만 처리 |
| `rate_hz` | 20.0 | Hz | `/cmd_vel` · 상태 발행 주기. 입력이 없어도 0을 계속 보낸다 |
| `timeout` | 0.5 | s | 마지막 입력을 **받은 시각**에서 이만큼 지나면 명령 0 (30 fps에서 약 15프레임) |
| `max_input_age` | 0.5 | s | 영상의 `header.stamp`가 이보다 오래되면 신선하지 않은 입력으로 보고 명령 0 |
| `stall_timeout` | 0.5 | s | 이 시간 동안 영상이 없으면 상태를 `CAMERA_STALL`로 발행 |

---

## detector.yaml

`tracker_node`가 `detector_config`로 읽는 검출 설정. 목표는 파란 30×30×60 mm 직육면체, 거리 0.1~1.0 m, 어두움~밝음 조명이다. 검출은 색 마스크 → 면적 → 모양 → 상자 판정 → 뎁스 검증 순서로 진행된다.

### target — 무엇을 찾는가

| 파라미터 | 값 | 의미 |
| --- | --- | --- |
| `name` | blue_cube | 사진 · 결과 JSON에 기록되는 목표 이름 |
| `hsv_ranges` | lower [104, 200, 8]<br>upper [120, 255, 255] | 목표 색의 OpenCV HSV 범위(H 0~179, S · V 0~255). 큐브 H 112 ± 8. S 하한 200은 배경(보라 의자 · 청회색 카펫, S 최대 약 163)을 거르는 값. 범위를 여러 개 적으면 합집합 |
| `min_chroma` | 5 | 색 세기(max − min) 하한. 어두운 픽셀에서 잡음으로 커진 S를 버린다 |
| `size_mm` | [30, 30, 60] | 목표 크기(가로 · 세로 · 높이, mm). 면적 기준 자동 계산에 쓴다 |
| `distance_range_m` | [0.1, 1.0] | 목표가 있을 거리 범위(m). 면적 기준 자동 계산에 쓴다 |

### camera — 카메라 설정

| 파라미터 | 값 | 의미 |
| --- | --- | --- |
| `backend` | realsense | `realsense`(pyrealsense2) 또는 `v4l2`(OpenCV, 예비용) |
| `device` | 6 | v4l2 장치 번호. `backend: v4l2`일 때만 사용 |
| `fps` | 30 | 프레임률 |
| `warmup_frames` | 30 | 자동 노출 · 화이트밸런스 안정화를 위해 처음에 버리는 프레임 수 |
| `exposure` | null | 컬러 노출(1~10000). null = 자동 — 조명 변화를 카메라가 흡수 |
| `white_balance` | 4600 | 화이트밸런스(2800~6500 K). 고정해야 색상 H가 흔들리지 않는다. 4600 K는 실험실에서 잰 자동값 |
| `options.auto_exposure_priority` | 1 | 1 = 어두우면 프레임률을 낮춰서라도 노출을 늘림(30 → 15 fps 가능) |
| `options.backlight_compensation` | 0 | 역광 보정 끔 |
| `fx_px` | 460.0 | 컬러 초점거리(px, `fx_width` 기준). 640×360은 약 460. RealSense 실행 시 실제 값으로 덮어쓴다 |
| `fx_width` | 640 | `fx_px`의 기준 영상 폭(px) |

### processing — 전처리

| 파라미터 | 값 | 의미 |
| --- | --- | --- |
| `width` | 640 | 처리 해상도 폭. 다른 크기 입력은 이 크기로 바꿔 처리 |
| `height` | 360 | 처리 해상도 높이. 비율이 다르면(640×480) 가운데를 16:9로 잘라 쓴다 |
| `blur_ksize` | 5 | 가우시안 블러 커널 크기(홀수, 0이면 생략) |
| `morph_kernel` | 5 | 모폴로지 커널 크기 |
| `open_iterations` | 1 | 열림 횟수 — 작은 점 잡음 제거 |
| `close_iterations` | 2 | 닫힘 횟수 — 물체 내부 구멍 · 틈 메우기 |

### selection — 후보 거르기와 고르기

| 파라미터 | 값 | 의미 |
| --- | --- | --- |
| `min_area` | auto | 뎁스가 없을 때의 최소 면적(px). auto = `min_area_factor` × (1 m에서 30×30 면의 넓이) |
| `min_area_factor` | 0.3 | 회전 · 가림 · 원근 여유. 640×360 · fx 460 · 1 m에서 약 57 px |
| `max_area_ratio` | auto | 화면 대비 최대 면적 비. auto = 0.1 m에서 30×60 면 기준(0.6~0.95) |
| `max_aspect` | 3.0 | 외접 사각형 긴 변 / 짧은 변 상한. 옆면은 2:1 — 긴 줄무늬 · 막대 제거 |
| `min_extent` | 0.60 | 면적 / 최소 외접 사각형 면적 하한. 홈이 있거나 구불구불한 덩어리 제거(큐브 0.84~0.99, 파란 브래킷 0.52) |
| `min_solidity` | 0.75 | 면적 / 볼록껍질 면적 하한. 오목한 물체 제거(큐브 0.91~1.00, 브래킷 0.67) |
| `tie_ratio` | 0.1 | 후보가 여럿이면 가장 큰 것을 고르되, 면적 차이가 10% 이내면 화면 중심에 가까운 것 |
| `center_method` | hull | 중심 계산 방식. 볼록껍질 중심 — 하이라이트 · 그늘에 덜 끌려간다 |

#### selection.box_fit — 상자 모양 판정

실루엣(볼록껍질)을 꼭짓점 `max_vertices` 이하 다각형으로 근사했을 때, 평균 틈이 `base + pixel / √넓이` 이하여야 상자로 본다. 원 · 타원 · 고리를 거른다.

| 파라미터 | 값 | 의미 |
| --- | --- | --- |
| `enabled` | true | 상자 판정 사용 여부 |
| `max_vertices` | 6 | 근사 다각형 꼭짓점 상한. 상자 실루엣은 4(정면)~6(비스듬)각형 |
| `base` | 0.02 | 허용 틈의 기본값 |
| `pixel` | 0.7 | 작은 실루엣일수록 틈을 더 허용하는 계수(500 px → 0.051, 5,000 px → 0.030) |
| `min_px` | 500 | 이보다 작은 실루엣(약 0.7 m보다 멂)은 해상도가 부족해 검사하지 않는다 |

#### selection.partial — 일부만 보이는 큐브

모양 · 넓이 기준에 걸려도 그 이유가 화면 가장자리에 잘림(border)이나 앞 물체에 가림(occluded)으로 설명되면 기준을 완화한다. 크기 상한은 그대로 둔다.

| 파라미터 | 값 | 의미 |
| --- | --- | --- |
| `enabled` | true | 일부 보임 완화 사용 여부 |
| `border_px` | 2 | 화면 가장자리에서 이 픽셀 이내면 잘린 것으로 본다 |
| `border_max_angle_deg` | 30 | 길쭉한 덩어리는 긴 변이 가장자리와 30° 이내로 나란해야 잘린 것(가로 띠 오검출 방지) |
| `max_aspect` | 8.0 | 완화된 장단비 상한(큐브 폭의 1/3만 보이면 약 7.6) |
| `min_extent` | 0.35 | 가림으로 설명될 때의 채움비 하한 |
| `min_solidity` | 0.5 | 가림으로 설명될 때의 solidity 하한 |
| `front_margin_m` | 0.01 | 큐브보다 max(1 cm, 거리 × `front_margin_ratio`) 이상 가까우면 '앞 물체' |
| `front_margin_ratio` | 0.015 | 위 기준의 거리 비례 항(D435 뎁스 오차보다 크고 손가락 두께보다 작게) |
| `front_ratio` | 0.6 | 오목부 뎁스의 60% 이상이 앞 물체면 가림으로 본다 |
| `ring_px` | 4 | 둘레 검사 폭(px) |
| `ring_front_ratio` | 0.2 | 바로 바깥 둘레의 20% 이상이 앞 물체면 가림(곧게 잘린 가림) |
| `occluder_exclude_ranges` | lower [95, 60, 20]<br>upper [130, 255, 255] | 이 HSV 범위(파란 계열)는 가린 물체로 치지 않는다 — 청바지 주름 오검출 방지 |
| `min_area_m2` | 0.0001 | 일부만 보일 때 실제 넓이 하한 1 cm²(평소 3 cm²) |

### depth — 뎁스 검증

컨투어 안 뎁스의 중앙값 Z로 실제 거리와 크기를 계산해 후보를 검증한다(RealSense만). 실제 길이 = 픽셀 길이 × Z / f.

| 파라미터 | 값 | 의미 |
| --- | --- | --- |
| `enabled` | true | 뎁스 검증 사용 여부 |
| `min_m` | 0.1 | 최소 거리(m). 이보다 가까워 뎁스가 0이면 색 · 면적 규칙으로 판단 |
| `max_m` | 1.1 | 최대 거리(m). 목표 1.0 m + 여유(1.0 m 실측 Z 1.01~1.03) |
| `min_valid_ratio` | 0.3 | 컨투어 안 유효(0이 아닌) 뎁스 픽셀 비율 하한 |
| `erode` | 1 | 경계 픽셀을 빼기 위한 침식 횟수(3×3) |
| `min_area_px` | 60 | 뎁스가 있을 때의 최소 면적(px, 잡음 바닥). 1 m 실측 최소 211 px |
| `no_depth_min_area` | 800 | 뎁스 측정 실패(너무 가까움 · 반사) 시 색만으로 믿을 최소 면적(px) |
| `max_short_m` | 0.06 | 실제 짧은 변 상한(m). 모서리가 카메라를 향한 자세(5.0~5.3 cm)까지 허용 |
| `max_long_m` | 0.08 | 실제 긴 변 상한(m) |
| `area_m2` | [0.0003, 0.0030] | 실제 넓이 범위 3~30 cm² |
| `split` | true | 같은 색 물체와 겹쳐 크기가 안 맞는 덩어리를 뎁스 경계에서 나눠 다시 검증 |
| `split_jump_m` | 0.02 | 이웃 픽셀 뎁스 차가 이보다 크면 다른 물체로 본다(m) |
| `split_jump_ratio` | 0.03 | 먼 거리 잡음 대비. 기준 = max(`split_jump_m`, 거리 × 이 값) |
| `split_min_valid` | 0.6 | 덩어리 안 유효 뎁스 비율이 이보다 낮으면 나누지 않는다 |

---

## control.yaml

`control_lite`(모터 구동 노드)의 ROS 파라미터.

| 파라미터 | 값 | 의미 |
| --- | --- | --- |
| `use_sim_time` | false | 시스템 시계를 쓴다(실제 하드웨어 구동) |

파일에 없는 설정:

- 시리얼 포트는 런치 인자 `port`로 넘긴다(기본 `/dev/ttyACM0`).
- 통신 속도는 115200 baud로 고정이다.
- 시작할 때 항상 한 번 원점(홈)을 잡는다.

---

## bag_qos.yaml

`ros2 bag play`로 녹화 영상을 재생할 때 토픽의 QoS를 덮어쓴다. 발행자와 구독자의 QoS가 맞지 않으면 연결되지 않으므로, `tracker_node`의 영상 구독 설정(reliable)에 맞춘다. `hardware_launch.py`에 `bag_path`를 주면 자동으로 적용된다.

적용 토픽(두 토픽 모두 같은 값):

- `/camera/color/image_raw` — 컬러 영상
- `/camera/aligned_depth_to_color/image_raw` — 컬러에 정렬된 뎁스 영상

| 파라미터 | 값 | 의미 | 반대 값 | 이 값을 쓰는 이유 |
| --- | --- | --- | --- | --- |
| `reliability` | `reliable` | 유실되면 재전송해 반드시 전달 | `best_effort` — 유실돼도 재전송 안 함 | tracker 구독 설정과 맞춰야 연결됨 |
| `durability` | `volatile` | 늦게 접속한 구독자에게 지난 메시지를 안 보냄 | `transient_local` — 마지막 메시지를 보관해 전달 | 영상은 지난 프레임이 필요 없음 |
| `history` | `keep_last` | 큐에 최근 N개만 보관 | `keep_all` — 전부 보관 | 메모리가 끝없이 쌓이지 않음 |
| `depth` | `5` | `keep_last`의 N. 최근 5프레임까지 보관 | — | 처리가 밀리면 오래된 프레임부터 버림 |

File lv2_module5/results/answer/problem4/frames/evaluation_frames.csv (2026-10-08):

scene | file | frame_id_ns | node_detected | target_visible | human_judgment | note
p4_normal2 | p4_normal2/1791337354150720000_1.jpg | 1791337354150720000 | 1 | visible | correct | ex=-0.516 ey=-0.721 Z=0.374m
p4_normal2 | p4_normal2/1791337354484475648_1.jpg | 1791337354484475648 | 1 | assumed_visible | unverified
p4_normal2 | p4_normal2/1791337354818057472_1.jpg | 1791337354818057472 | 1 | assumed_visible | unverified
p4_normal2 | p4_normal2/1791337355151542016_1.jpg | 1791337355151542016 | 1 | assumed_visible | unverified
p4_normal2 | p4_normal2/1791337355484875264_1.jpg | 1791337355484875264 | 1 | assumed_visible | unverified
p4_normal2 | p4_normal2/1791337355818039296_1.jpg | 1791337355818039296 | 1 | assumed_visible | unverified
p4_normal2 | p4_normal2/1791337356151410432_1.jpg | 1791337356151410432 | 1 | assumed_visible | unverified
p4_normal2 | p4_normal2/1791337356484994048_1.jpg | 1791337356484994048 | 1 | assumed_visible | unverified
p4_normal2 | p4_normal2/1791337356818575616_1.jpg | 1791337356818575616 | 1 | assumed_visible | unverified
p4_normal2 | p4_normal2/1791337357152155648_1.jpg | 1791337357152155648 | 1 | assumed_visible | unverified
p4_normal2 | p4_normal2/1791337357485734144_1.jpg | 1791337357485734144 | 1 | assumed_visible | unverified
p4_normal2 | p4_normal2/1791337357819310336_1.jpg | 1791337357819310336 | 1 | assumed_visible | unverified
p4_normal2 | p4_normal2/1791337358152881408_1.jpg | 1791337358152881408 | 1 | assumed_visible | unverified
p4_normal2 | p4_normal2/1791337358486447872_1.jpg | 1791337358486447872 | 1 | assumed_visible | unverified
p4_normal2 | p4_normal2/1791337358820011008_1.jpg | 1791337358820011008 | 1 | assumed_visible | unverified
p4_normal2 | p4_normal2/1791337359153574656_1.jpg | 1791337359153574656 | 1 | assumed_visible | unverified
p4_normal2 | p4_normal2/1791337359487138048_1.jpg | 1791337359487138048 | 1 | assumed_visible | unverified
p4_normal2 | p4_normal2/1791337359820698624_1.jpg | 1791337359820698624 | 1 | assumed_visible | unverified
p4_normal2 | p4_normal2/1791337360154268160_1.jpg | 1791337360154268160 | 1 | assumed_visible | unverified
p4_normal2 | p4_normal2/1791337360487843328_1.jpg | 1791337360487843328 | 1 | assumed_visible | unverified
p4_normal2 | p4_normal2/1791337360821418240_1.jpg | 1791337360821418240 | 1 | assumed_visible | unverified
p4_normal2 | p4_normal2/1791337361154993920_1.jpg | 1791337361154993920 | 1 | assumed_visible | unverified
p4_normal2 | p4_normal2/1791337361488570112_1.jpg | 1791337361488570112 | 1 | assumed_visible | unverified
p4_normal2 | p4_normal2/1791337361822146560_0.jpg | 1791337361822146560 | 0 | visible | miss | 역광 — 큐브 보이나 미검출
p4_normal2 | p4_normal2/1791337362155721472_0.jpg | 1791337362155721472 | 0 | visible | miss | 역광 — 앞뒤 프레임과 같은 구간
p4_normal2 | p4_normal2/1791337362489295616_0.jpg | 1791337362489295616 | 0 | visible | miss | 역광 — 큐브 보이나 미검출
p4_normal2 | p4_normal2/1791337362822869504_1.jpg | 1791337362822869504 | 1 | assumed_visible | unverified
p4_normal2 | p4_normal2/1791337363156443392_1.jpg | 1791337363156443392 | 1 | assumed_visible | unverified
p4_normal2 | p4_normal2/1791337363490017536_1.jpg | 1791337363490017536 | 1 | assumed_visible | unverified
p4_normal2 | p4_normal2/1791337363823591680_1.jpg | 1791337363823591680 | 1 | assumed_visible | unverified
p4_normal2 | p4_normal2/1791337364157167360_1.jpg | 1791337364157167360 | 1 | assumed_visible | unverified
p4_normal2 | p4_normal2/1791337364490744320_1.jpg | 1791337364490744320 | 1 | assumed_visible | unverified
p4_normal2 | p4_normal2/1791337364824321536_1.jpg | 1791337364824321536 | 1 | assumed_visible | unverified
p4_normal2 | p4_normal2/1791337365157897472_1.jpg | 1791337365157897472 | 1 | assumed_visible | unverified
p4_normal2 | p4_normal2/1791337365491472640_1.jpg | 1791337365491472640 | 1 | assumed_visible | unverified
p4_normal2 | p4_normal2/1791337365825047552_1.jpg | 1791337365825047552 | 1 | assumed_visible | unverified
p4_normal2 | p4_normal2/1791337366158623488_1.jpg | 1791337366158623488 | 1 | assumed_visible | unverified
p4_normal2 | p4_normal2/1791337366492200448_1.jpg | 1791337366492200448 | 1 | assumed_visible | unverified
p4_normal2 | p4_normal2/1791337366825777152_1.jpg | 1791337366825777152 | 1 | assumed_visible | unverified
p4_normal2 | p4_normal2/1791337367159354624_1.jpg | 1791337367159354624 | 1 | assumed_visible | unverified
p4_normal2 | p4_normal2/1791337367492933376_1.jpg | 1791337367492933376 | 1 | assumed_visible | unverified
p4_normal2 | p4_normal2/1791337367826511872_1.jpg | 1791337367826511872 | 1 | assumed_visible | unverified
p4_normal2 | p4_normal2/1791337368160091648_1.jpg | 1791337368160091648 | 1 | assumed_visible | unverified
p4_normal2 | p4_normal2/1791337368493671680_1.jpg | 1791337368493671680 | 1 | assumed_visible | unverified
p4_normal2 | p4_normal2/1791337368827252224_1.jpg | 1791337368827252224 | 1 | assumed_visible | unverified
p4_normal2 | p4_normal2/1791337369160829696_1.jpg | 1791337369160829696 | 1 | assumed_visible | unverified
p4_normal2 | p4_normal2/1791337369494405376_1.jpg | 1791337369494405376 | 1 | assumed_visible | unverified
p4_normal2 | p4_normal2/1791337369827980800_1.jpg | 1791337369827980800 | 1 | assumed_visible | unverified
p4_normal2 | p4_normal2/1791337370161557248_1.jpg | 1791337370161557248 | 1 | assumed_visible | unverified
p4_normal2 | p4_normal2/1791337370495134464_1.jpg | 1791337370495134464 | 1 | assumed_visible | unverified
p4_normal2 | p4_normal2/1791337370828711680_1.jpg | 1791337370828711680 | 1 | assumed_visible | unverified
p4_normal2 | p4_normal2/1791337371162289408_1.jpg | 1791337371162289408 | 1 | assumed_visible | unverified
p4_normal2 | p4_normal2/1791337371495866880_1.jpg | 1791337371495866880 | 1 | assumed_visible | unverified
p4_normal2 | p4_normal2/1791337371829444608_1.jpg | 1791337371829444608 | 1 | assumed_visible | unverified
p4_normal2 | p4_normal2/1791337372163021824_1.jpg | 1791337372163021824 | 1 | assumed_visible | unverified
p4_normal2 | p4_normal2/1791337372496598272_1.jpg | 1791337372496598272 | 1 | assumed_visible | unverified
p4_normal2 | p4_normal2/1791337372830174720_1.jpg | 1791337372830174720 | 1 | assumed_visible | unverified
p4_normal2 | p4_normal2/1791337373163753472_1.jpg | 1791337373163753472 | 1 | assumed_visible | unverified
p4_normal2 | p4_normal2/1791337373497333248_1.jpg | 1791337373497333248 | 1 | assumed_visible | unverified
p4_normal2 | p4_normal2/1791337373830913024_1.jpg | 1791337373830913024 | 1 | visible | correct | ex=-0.047 ey=-0.011 Z=0.477m
p4_normal2 | p4_normal2/1791337374164489984_1.jpg | 1791337374164489984 | 1 | assumed_visible | unverified
p4_normal2 | p4_normal2/1791337374498064896_1.jpg | 1791337374498064896 | 1 | assumed_visible | unverified
p4_normal2 | p4_normal2/1791337374831639552_1.jpg | 1791337374831639552 | 1 | assumed_visible | unverified
p4_normal2 | p4_normal2/1791337375165217280_1.jpg | 1791337375165217280 | 1 | assumed_visible | unverified
p4_normal2 | p4_normal2/1791337375498796800_1.jpg | 1791337375498796800 | 1 | assumed_visible | unverified
p4_normal2 | p4_normal2/1791337375832376832_1.jpg | 1791337375832376832 | 1 | assumed_visible | unverified
p4_normal2 | p4_normal2/1791337376165956608_0.jpg | 1791337376165956608 | 0 | visible | miss | 역광 — 마스크가 큐브 일부만
p4_normal2 | p4_normal2/1791337376499536384_0.jpg | 1791337376499536384 | 0 | visible | miss | 역광 — 마스크가 큐브 일부만
p4_normal2 | p4_normal2/1791337376833116160_1.jpg | 1791337376833116160 | 1 | assumed_visible | unverified
p4_normal2 | p4_normal2/1791337377166695936_1.jpg | 1791337377166695936 | 1 | assumed_visible | unverified
p4_normal2 | p4_normal2/1791337377500275712_1.jpg | 1791337377500275712 | 1 | assumed_visible | unverified
p4_normal2 | p4_normal2/1791337377833855488_1.jpg | 1791337377833855488 | 1 | assumed_visible | unverified
p4_normal2 | p4_normal2/1791337378167432704_1.jpg | 1791337378167432704 | 1 | assumed_visible | unverified
p4_normal2 | p4_normal2/1791337378501007360_1.jpg | 1791337378501007360 | 1 | assumed_visible | unverified
p4_normal2 | p4_normal2/1791337378834582016_1.jpg | 1791337378834582016 | 1 | assumed_visible | unverified
p4_normal2 | p4_normal2/1791337379168157184_1.jpg | 1791337379168157184 | 1 | assumed_visible | unverified
p4_normal2 | p4_normal2/1791337379501732352_1.jpg | 1791337379501732352 | 1 | assumed_visible | unverified
p4_normal2 | p4_normal2/1791337379835307776_1.jpg | 1791337379835307776 | 1 | assumed_visible | unverified
p4_normal2 | p4_normal2/1791337380168886528_1.jpg | 1791337380168886528 | 1 | assumed_visible | unverified
p4_normal2 | p4_normal2/1791337380502467840_1.jpg | 1791337380502467840 | 1 | assumed_visible | unverified
p4_normal2 | p4_normal2/1791337380836049152_1.jpg | 1791337380836049152 | 1 | assumed_visible | unverified
p4_normal2 | p4_normal2/1791337381169625088_1.jpg | 1791337381169625088 | 1 | assumed_visible | unverified
p4_normal2 | p4_normal2/1791337381503196416_1.jpg | 1791337381503196416 | 1 | assumed_visible | unverified
p4_normal2 | p4_normal2/1791337381836767744_1.jpg | 1791337381836767744 | 1 | assumed_visible | unverified
p4_normal2 | p4_normal2/1791337382170340864_1.jpg | 1791337382170340864 | 1 | assumed_visible | unverified
p4_normal2 | p4_normal2/1791337382503914752_1.jpg | 1791337382503914752 | 1 | assumed_visible | unverified
p4_normal2 | p4_normal2/1791337382837488896_1.jpg | 1791337382837488896 | 1 | assumed_visible | unverified
p4_normal2 | p4_normal2/1791337383171064832_1.jpg | 1791337383171064832 | 1 | assumed_visible | unverified
p4_normal2 | p4_normal2/1791337383504643072_1.jpg | 1791337383504643072 | 1 | assumed_visible | unverified
p4_normal2 | p4_normal2/1791337383838221312_1.jpg | 1791337383838221312 | 1 | visible | correct | ex=+0.051 ey=-0.052 Z=0.337m
p4_normal2 | p4_normal2/1791337384171799040_1.jpg | 1791337384171799040 | 1 | assumed_visible | unverified
p4_normal2 | p4_normal2/1791337384505376256_1.jpg | 1791337384505376256 | 1 | assumed_visible | unverified
p4_normal2 | p4_normal2/1791337384838953728_1.jpg | 1791337384838953728 | 1 | assumed_visible | unverified
p4_normal2 | p4_normal2/1791337385172531456_1.jpg | 1791337385172531456 | 1 | assumed_visible | unverified
p4_normal2 | p4_normal2/1791337385506109696_1.jpg | 1791337385506109696 | 1 | assumed_visible | unverified
p4_normal2 | p4_normal2/1791337385839687424_1.jpg | 1791337385839687424 | 1 | assumed_visible | unverified
p4_normal2 | p4_normal2/1791337386173264640_1.jpg | 1791337386173264640 | 1 | assumed_visible | unverified
p4_normal2 | p4_normal2/1791337386506840832_1.jpg | 1791337386506840832 | 1 | assumed_visible | unverified
p4_normal2 | p4_normal2/1791337386840417280_1.jpg | 1791337386840417280 | 1 | assumed_visible | unverified
p4_normal2 | p4_normal2/1791337387173993216_1.jpg | 1791337387173993216 | 1 | assumed_visible | unverified
p4_empty | p4_empty/1791336836104335872_0.jpg | 1791336836104335872 | 0 | absent | true_negative | 큐브 없음 · 미검출
p4_empty | p4_empty/1791336836438094336_0.jpg | 1791336836438094336 | 0 | assumed_absent | unverified
p4_empty | p4_empty/1791336836771657728_0.jpg | 1791336836771657728 | 0 | assumed_absent | unverified
p4_empty | p4_empty/1791336837105111296_0.jpg | 1791336837105111296 | 0 | assumed_absent | unverified
p4_empty | p4_empty/1791336837438388992_0.jpg | 1791336837438388992 | 0 | assumed_absent | unverified
p4_empty | p4_empty/1791336837771470592_0.jpg | 1791336837771470592 | 0 | assumed_absent | unverified
p4_empty | p4_empty/1791336838104807936_0.jpg | 1791336838104807936 | 0 | assumed_absent | unverified
p4_empty | p4_empty/1791336838438405888_0.jpg | 1791336838438405888 | 0 | assumed_absent | unverified
p4_empty | p4_empty/1791336838772006144_0.jpg | 1791336838772006144 | 0 | assumed_absent | unverified
p4_empty | p4_empty/1791336839105590272_0.jpg | 1791336839105590272 | 0 | assumed_absent | unverified
p4_empty | p4_empty/1791336839439158784_0.jpg | 1791336839439158784 | 0 | assumed_absent | unverified
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

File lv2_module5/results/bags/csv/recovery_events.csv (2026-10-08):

file | kind | t_lost | stop_ok | stop_delay | t_last_in | timeout_s | t_reappear | t_recover | recover_s | success
track_p4_ctrl_20261006_205122.csv | LOST | 12.47 | True | 0.048 |  |  | 12.579 | 12.67 | 0.091 | True
track_p4_ctrl_20261006_205122.csv | LOST | 12.77 | True | 0.048 |  |  | 12.945 | 13.018 | 0.073 | True
track_p4_ctrl_20261006_205122.csv | LOST | 18.368 | True | 0.049 |  |  | 18.649 | 18.717 | 0.068 | True
track_p4_ctrl_20261006_205122.csv | LOST | 23.619 | True | 0.052 |  |  | 23.719 | 23.819 | 0.1 | True
track_p4_ctrl_20261006_205122.csv | LOST | 24.072 | True | 0.047 |  |  | 24.454 | 24.57 | 0.116 | True
track_p4_input_20261006_205151.csv | TIMEOUT | 13.696 | True | 0.05 | 13.155 | 0.541 |  |  |  | False
track_p4_normal_20261006_205250.csv | LOST | 5.61 | True | 0.05 |  |  | 6.736 | 6.81 | 0.074 | True
track_p4_normal_20261006_205250.csv | LOST | 7.46 | True | 0.051 |  |  | 8.138 | 8.46 | 0.322 | True
track_p4_normal_20261006_205250.csv | LOST | 10.11 | True | 0.05 |  |  | 11.175 | 11.26 | 0.085 | True
track_p4_normal_20261006_205250.csv | LOST | 12.262 | True | 0.05 |  |  | 13.044 | 13.161 | 0.117 | True
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

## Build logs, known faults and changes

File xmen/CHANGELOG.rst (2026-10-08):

^^^^^^^^^^^^^^^^^^^^^^^^^^
Changelog for package xmen
^^^^^^^^^^^^^^^^^^^^^^^^^^

1.0.0 (2026-10-08)
------------------
First release of the ROS-Vision-Tracker stack for ROS 2 Lyrical on
Ubuntu 26.04 (ARM64). ``xmen`` is a metapackage; it installs
``xmen_tracker``, ``xmen_control``, ``xmen_description`` and ``xmen_bringup``.

Perception (``xmen_tracker``)
* Add RealSense capture publishing color and aligned depth, with a direct
  pipeline and an RGBD-subscription source selectable at launch.
* Add ``cube_detector``: HSV color segmentation plus real-world size and shape
  checks against the depth image, so a blue background or a partially visible
  cube no longer passes as the target.
* Bridge brief occlusions with a CSRT tracker and publish ``/tracking/bbox``.
* Add the annotated JPEG preview and RViz2 marker and point cloud overlays.
* Tune HSV, depth and focal-length values against measurements taken in the
  lab, including brightness correction for the real room.
* Fix QoS settings so the published image and marker topics are compatible
  with RViz2.
* Fix rosbag timestamp synchronization for color and depth replay.

Control (``xmen_control``)
* Add the OpenCR serial driver: angular velocity commands out (``V``), current
  angle in (``P``), ``/joint_states`` published, and travel limited per axis.
* Apply pan and tilt commands simultaneously rather than one axis at a time.
* Replace the original driver with the compact ``control_lite`` version.
* Standardize the gimbal velocity command topic as ``/cmd_vel``.
* Raise the motor time-delay limit and lower the default tracking speed to
  stop the overshoot seen on the real rig.

Description (``xmen_description``)
* Add the pan/tilt URDF, CAD meshes and the RViz2 configuration.

Bringup (``xmen_bringup``)
* Add the full hardware launch, the remote visualization launch and
  ``tracking.yaml``.
* Add ``robot_state_publisher``, ``joint_state_publisher`` and rosbag record
  and replay wiring.
* Default launch targets 30 Hz image publication, 20 Hz tracking, 20 Hz
  commands and a 5 Hz preview.

Firmware
* Add ``opencr_lite.ino`` and a prebuilt ARM64 flashing bundle
  (``firmware/opencr.tar.gz``) that needs no Arduino toolchain on the Pi.

Documentation and tooling
* Add the project README, per-package READMEs, parameter reference,
  RealSense setup notes and the problem reports with measured plots.
* Add the GitHub Actions workflow that builds the Raspberry Pi release
  tarball.

* Contributors: HaeminKim, HongjuLee, SeokMin Hong, chj1319, hsmint

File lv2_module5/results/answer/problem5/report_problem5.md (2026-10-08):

# 문제 5 — bag 재현과 팀 협업

## 1. 구현 내용

| 항목 | 내용 | 위치 |
|---|---|---|
| 기록 | 대표 성공 장면·소실/복귀 장면을 영상·뎁스·목표·명령·관절 토픽과 함께 기록 | `~/bags/p5_success`, `~/bags/p5_loss_return` |
| 메타데이터 | bag마다 `metadata.yaml` + `bag_info.txt`(해상도·토픽·메시지 수·기간) + 실행 당시 설정 3종 + `uncommitted.diff` | 각 bag 폴더 |
| 입력 재처리 | bag 영상만 재생 → `tracker_node`로 다시 검출 → `/target_replay` 등 별도 토픽으로 기록 | `~/bags/p5_*_replay` |
| 결과 재분석 | 저장된 `/target`·`/cmd_vel`에서 FPS·검출 출력 비율·RMSE·소실 이벤트 재계산, 재처리 결과와 프레임별 대조 | `replay_info.txt`, `compare.csv` |
| 다른 팀원 실행 | 다른 PC에서 `p5_success` 입력 재처리 + RViz 확인 | 4절, `pic/third_party_replay_rviz.png` |

## 2. 기록 (bag)

### 2.1 기록 조건

| 항목 | 값 |
|---|---|
| 해상도 | 640 × 360 (컬러·정렬 뎁스) |
| 카메라 설정 FPS | 30 |
| 저장 형식 | mcap |
| 검출 설정 | `detector.yaml` (파란 30×30×60 mm 직육면체, H 104~120 · S 200~255 · V 8~255) |
| 추적 설정 | `tracker.yaml` — `tracker_type: fusion`, Kp 1.5 (팬) / 1.2 (틸트), 데드밴드 0.05, 속도 상한 0.9 / 0.6 rad/s, 처리 15 Hz, 명령 20 Hz, 타임아웃 0.5 s |
| 구동 설정 | `control.yaml` — `control_lite`, 115200 baud, 시작 시 홈 복귀 |
| 실제 구동 | 녹화 중 모터 출력 켬(폐루프). `/joint_states` 약 48 Hz. 팬 −0.37~−0.06 rad · 틸트 −0.17~0.20 rad (`p5_success`), 팬 −0.03~0.06 rad · 틸트 −0.06~0.37 rad (`p5_loss_return`) |

기록 명령 (보드):

```bash
ros2 bag record -s mcap -o ~/bags/p5_success \
  /camera/color/image_raw /camera/aligned_depth_to_color/image_raw /camera/color/camera_info \
  /target /cmd_vel /perception_status /joint_states
```
(확인 필요 — 실제 사용한 명령으로 교체)

### 2.2 bag 메타데이터

| bag | 장면 | 기간 [s] | 크기 | 메시지 수 | SHA-256 (mcap) |
|---|---|---|---|---|---|
| `p5_success` | 대표 성공 | 47.81 | 912.0 MiB | 4864 | `f2d9a2c3…8b7594638` |
| `p5_loss_return` | 소실·복귀 | 29.48 | 575.0 MiB | 3101 | `34fc72b6…1e63938` |

<details><summary>SHA-256 전체</summary>

```
f2d9a2c33547641fc7f84f8fb68dab871acf54decc5ad8fee0d890e072835fdb  p5_success/0_p5_success_2026_10_08-10_13_52.mcap
34fc72b612c7951e1482b66602929717cd66bacc1768d0ef6c9fc4c8b7594638  p5_loss_return/0_p5_loss_return_2026_10_08-10_24_02.mcap
4e73e3c181ef73643a27947f4c27bcf80aef67b797c31f2d99673df3a8744ffc  p5_success_replay/0_p5_success_replay_2026_10_08-11_56_18.mcap
481a5b2b612f663c9b8f0e337e6ce3368b89c8b27f5075fc82806bb4f1e63938  p5_loss_return_replay/0_p5_loss_return_replay_2026_10_08-11_58_16.mcap
```
</details>

| 토픽 | 타입 | `p5_success` | `p5_loss_return` |
|---|---|---|---|
| `/camera/color/image_raw` | sensor_msgs/Image | 594 | 374 |
| `/camera/aligned_depth_to_color/image_raw` | sensor_msgs/Image | 591 | 373 |
| `/camera/color/camera_info` | sensor_msgs/CameraInfo | 592 | 374 |
| `/target` | geometry_msgs/PointStamped | 353 | 247 |
| `/cmd_vel` | geometry_msgs/Twist | 418 | 326 |
| `/perception_status` | std_msgs/String | 42 | 54 |
| `/joint_states` | sensor_msgs/JointState | 2274 | 1353 |

## 3. 재현

두 재현 모두 **모터 출력 없이** 수행했다(PC에서 control 미실행, 보드 연결 없음). 원본 bag은 실제 모터를 구동하며 기록한 것이고(2.1), 재현은 오프라인이다.

| 재현 | 수행 내용 | 확인 |
|---|---|---|
| 입력 재처리 | bag의 영상 3토픽만 재생 → `tracker_node`가 다시 검출, 출력은 `/target_replay`·`/cmd_vel_replay`·`/perception_status_replay` | 같은 설정에서 검출·오차 경향이 재현되는가 |
| 결과 재분석 | bag에 저장된 `/target`·`/cmd_vel`만으로 지표 재계산 | 기존 성능표와 같은가 |

### 3.1 입력 재처리 명령

```bash
# 터미널 1 — 검출기 (원본 /target과 섞이지 않게 remap, bag 시간 사용)
ros2 run xmen_tracker tracker_node --ros-args \
  --params-file ~/bags/p5_success/tracker.yaml \
  -p detector_config:=$HOME/bags/p5_success/detector.yaml \
  -p use_sim_time:=true \
  -r /target:=/target_replay -r /cmd_vel:=/cmd_vel_replay \
  -r /perception_status:=/perception_status_replay

# 터미널 2 — 영상만 재생, 촬영 시각을 /clock으로
ros2 bag play ~/bags/p5_success --clock-topics /camera/color/image_raw \
  --qos-profile-overrides-path ~/bags/replay_qos.yaml \
  --topics /camera/color/image_raw /camera/aligned_depth_to_color/image_raw /camera/color/camera_info

# 터미널 3 — 재처리 결과 기록
ros2 bag record -s mcap -o ~/bags/p5_success_replay \
  /target_replay /cmd_vel_replay /perception_status_replay
```

- 저장된 `/target`·`/cmd_vel`은 `--topics`로 재생하지 않으므로 새 결과와 같은 토픽에 섞이지 않는다.
- `--clock-topics`로 촬영 시각이 `/clock`이 되고 tracker는 `use_sim_time:=true`이므로, 타임아웃·지연에 현재 벽시계가 섞이지 않는다.

### 3.2 결과 — 대표 성공 (`p5_success`)

| 지표 | 원본 `/target` (결과 재분석) | 재처리 `/target_replay` (입력 재처리) |
|---|---|---|
| 프레임 수 | 353 (47.13 s) | 382 (47.75 s) |
| 처리 FPS | 7.47 | 7.98 |
| 검출 출력 비율 | 87.8% (310 / 353) | 92.1% (352 / 382) |
| 수평 RMSE (ex) | 0.079 (검출 310) | 0.080 (검출 352) |
| 수직 RMSE (ey) | 0.110 | 0.128 |
| 최대 \|ex\| | 0.355 | 0.357 |
| 소실 | 8회 | 6회 |

같은 촬영 시각 프레임 대조 (`compare.csv`):

| 항목 | 값 |
|---|---|
| 짝 프레임 | 222 |
| 검출 여부 일치 | 95.0% (211 / 222). 불일치 11개는 모두 원본 미검출 → 재처리 검출 |
| \|Δex\| 평균 / 최대 (둘 다 검출 196개) | 0.0006 / 0.0054 |

### 3.3 결과 — 소실·복귀 (`p5_loss_return`)

| 지표 | 원본 `/target` (결과 재분석) | 재처리 `/target_replay` (입력 재처리) |
|---|---|---|
| 프레임 수 | 247 (29.08 s) | 242 (27.62 s) |
| 처리 FPS | 8.46 | 8.72 |
| 검출 출력 비율 | 40.5% (100 / 247) | 42.1% (102 / 242) |
| 수평 RMSE (ex) | 0.124 (검출 100) | 0.078 (검출 102) |
| 수직 RMSE (ey) | 0.356 | 0.297 |
| 최대 \|ex\| | 0.985 | 0.130 |
| 소실 | 18회 (마지막 1회 재검출 없음) | 8회 (마지막 1회 재검출 없음) |
| 소실 후 정지까지 | 0.001~0.027 s | 0.000 s |

같은 촬영 시각 프레임 대조:

| 항목 | 값 |
|---|---|
| 짝 프레임 | 143 |
| 검출 여부 일치 | 81.8% (117 / 143). 불일치 26개 = 원본만 검출 7 · 재처리만 검출 19 |
| \|Δex\| 평균 / 최대 (둘 다 검출 41개) | 0.0010 / 0.0042 |

## 4. 다른 팀원 실행 기록

### 4.1 실행 명령 (원본 로그: [third_party_log.txt](third_party_log.txt))

```bash
# 저장소: ~/Documents/temp/ROS-Vision-Tracker, bag: ~/bags/p5/p5_success
ros2 run xmen_tracker tracker_node --ros-args \
  --params-file $HOME/bags/p5/p5_success/tracker.yaml \
  -p detector_config:=$HOME/bags/p5/p5_success/detector.yaml \
  -p use_sim_time:=true -p debug_timing:=true \
  -r /target:=/target_replay -r /cmd_vel:=/cmd_vel_replay \
  -r /perception_status:=/perception_status_replay

ros2 bag play ~/bags/p5/p5_success --clock
```

### 4.2 결과

다른 PC 재처리 — RViz

*다른 PC에서 `p5_success` 재처리 중인 RViz. 왼쪽 위 Tracking Image에 큐브 검출 박스, 오른쪽에 로봇 모델과 이미지 평면*

| 항목 | 값 |
|---|---|
| 검출 설정 로드 | HSV [104,200,8]~[120,255,255], min_area 57 px, depth 0.1~1.1 m — `detector.yaml`과 같음 |
| sim time | `now`가 bag 시각(1791422034~046 s)을 따라감, `stale 0` |
| 처리량 (2 s마다) | 동기화 40~45쌍 중 24~30개 처리 → 약 12~15 FPS (보드 원본 약 13.7 FPS, 기록 공백 제외) |

## 5. 해석

1. **검출기 자체는 재현된다.** 두 bag 모두 원본·재처리가 함께 검출한 프레임에서 |Δex| 최대 0.0054로, 같은 영상·같은 설정이면 중심 오차는 사실상 같다.
2. **차이는 "어떤 프레임을 처리했는가"에서 나온다.** 짝 프레임이 원본 프레임의 63%(222/353)·58%(143/247)뿐이다. tracker가 15 Hz로 가장 최근 프레임만 처리하므로(`tracking_hz: 15`) 보드와 PC에서 건너뛴 프레임이 달라진다. fusion 추적기는 KCF·SIFT 상태를 이어 쓰므로, 처리한 프레임이 다르면 다음 프레임의 검출 여부도 달라질 수 있다. 소실·복귀 bag에서 불일치(18.2%)가 큰 것은 목표가 가려지고 나타나는 경계 프레임이 많기 때문으로 보인다. (가설 — 확인 필요)
3. 소실·복귀 bag의 최대 |ex|가 0.985 → 0.130으로 크게 다른 것은 원본의 한 프레임(8.49 s) 때문이다. 화면 왼쪽 끝 모니터 가장자리를 면적비 0.0005로 잘못 검출한 배경 오검출이다(3.4 이미지). 이 프레임은 재처리에서 짝이 없어(그 촬영 시각을 처리하지 않음) 재처리 쪽 결과는 알 수 없다. |ex| > 0.3인 원본 검출은 이 1프레임뿐이다.
4. 처리 FPS가 7.5~8.7로 문제 4(29.98)보다 낮다. 다만 이 FPS는 기록 공백을 포함한 전체 시간으로 나눈 값이다. 문제 4는 `target_detector`, 문제 5는 `tracker_node`(fusion, 뎁스·SIFT 포함)로 검출기가 다르다. 문제 4 성능표와 수치를 직접 비교하지 않는다.
5. 명령 수가 원본 418 vs 재처리 961로 다르다. 원본은 기록 공백(약 21.4 s) 동안 명령이 거의 없었고(5개), 공백을 빼면 약 16 Hz(명령 간격 중앙값 0.062 s)였다. 재처리는 PC에서 sim time 기준 20 Hz 타이머가 그대로 돌았다. 공백을 뺀 나머지 차이(16 vs 20 Hz)는 보드 부하로 타이머가 밀린 것으로 보인다. (가설)
6. 원본 `/target`의 수신 − 촬영 시각은 중앙값 0.25 s / 0.17 s, 최대 0.41 s / 0.47 s였다(`p5_success` / `p5_loss_return`). 입력 신선도 한계 `max_input_age` 0.5 s에 가까워, 보드 부하가 조금만 늘어도 신선한 입력이 TIMEOUT으로 처리될 수 있다.
7. 소실 중 정지는 실제 모터로 확인된다. `p5_loss_return`의 의도한 가림(2.46~8.49 s, 6.0 s) 동안 마지막 명령으로 틸트가 0.006 rad 더 움직인 뒤(2.46~2.52 s), 나머지 구간은 팬·틸트 모두 0.003 rad 이내로 멈춰 있었다. `p5_success`의 미검출 구간(32.1~33.8 s)도 팬 0.002 rad, 틸트 0 rad 변화였다(`/joint_states` 48 Hz 기준). 

## 6. 입력 재처리 vs 결과 재분석

| | 입력 재처리 | 결과 재분석 |
|---|---|---|
| 입력 | bag의 **영상**(컬러·뎁스·camera_info) | bag의 **저장된 출력**(`/target`·`/cmd_vel`) |
| 검출기 실행 | 함 (현재 코드·설정) | 안 함 |
| 확인하는 것 | 검출·제어 코드가 같은 입력에 같은 결과를 내는가 (코드 회귀) | 당시 기록으로 계산한 지표가 성능표와 같은가 (계산 재현) |

## 7. 원본 파일

| 파일 | 내용 |
|---|---|
| `~/bags/p5_*/metadata.yaml`, `bag_info.txt` | bag 메타데이터 |
| `~/bags/p5_*/{detector,tracker,control}.yaml` | 녹화 당시 설정 |
| `~/bags/p5_*_replay/replay_info.txt` | 재처리 명령·원본/재처리 지표 |
| `~/bags/p5_*_replay/compare.csv` | 프레임별 대조 (`stamp_ns, det_orig, ex_orig, ey_orig, det_replay, ex_replay, ey_replay`) |
| `report/problem5/third_party_log.txt` | 다른 PC 재처리 터미널 로그 (bag play·tracker_node) |
| `report/problem5/pic/third_party_replay_rviz.png` | 다른 PC 재처리 RViz 화면 |

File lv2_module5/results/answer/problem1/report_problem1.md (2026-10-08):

1. 배경과 구분되는 단일 색상 목표 1개를 선정
목표: 파란색 30×30×60 mm 직육면체(블루 큐브)
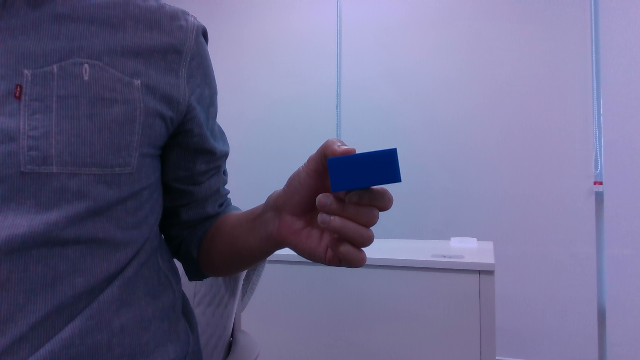
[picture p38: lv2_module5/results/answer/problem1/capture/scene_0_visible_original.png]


2. 영상 → HSV 변환 → 색상 마스크 → 잡음 제거 → 컨투어 → 대상 선택 → 중심 계산
   
| 단계 | 함수 (`detector.py`) | 내용 |
| --- | --- | --- |
| 0. 해상도 맞춤 | preprocess() | 처리 해상도 640×360. 비율이 다른 입력(640×480 사진)은 늘리지 않고 가운데를 16:9로 잘라 쓴다. 원본 좌표 복원 정보 Geometry 반환. |
| 1. HSV 변환 | color_mask() | 가우시안 블러 → cv2.cvtColor(BGR2HSV) |
| 2. 색상 마스크 | in_ranges() | cv2.inRange(H 104~120, S 200~255, V 8~255). 색 세기(max−min) 5 미만 픽셀 제외. |
| 3. 잡음 제거 | color_mask() | 5×5 타원 커널 열림 1회(점 잡음 제거) → 닫힘 2회(구멍 메움) |
| 4. 컨투어 | detect() | cv2.findContours(RETR_EXTERNAL) 외곽 컨투어 |
| 5. 후보 판정 | evaluate() | 면적 → 모양(장변/단변·채움비·solidity) → 뎁스 거리 범위·실제 크기 |
| 6. 대상 선택 | select() | 면적이 가장 큰 것. 면적 차이가 tie_ratio(10%) |
| 7. 중심 계산 | evaluate() | 모멘트 중심 `m10/m00, m01/m00` (`m00 = 0`이면 `zero_moment`로 탈락) |
| 8. 원본 좌표·오차 | to_original(), normalized_error() | 처리 좌표 → 실제 프레임 좌표, ex·ey, 면적비 |

2. HSV 범위·최소 면적·해상도를 설정 파일로 분리하고 여러 후보 중 선택 규칙
   면적·모양·뎁스 검사를 모두 통과한 후보만 남긴다.
   남은 후보 중 면적이 가장 큰 것, 면적 차이가 tie_ratio(10%) 이내인 후보끼리는 영상 중심에 더 가까운 것.

| 구분 | 키 | 값 |
| --- | --- | --- |
| HSV 범위  | target.hsv_ranges | lower `[104, 200, 8]`, upper `[120, 255, 255]` (빨강처럼 0/179를 넘는 색은 범위를 2개 적으면 합집합) |
| 색 세기 하한 | target.min_chroma | 5 |
| 해상도 | processing.width/height | 640 × 360 (D435 컬러·뎁스 모두 지원) |
| 잡음 제거 | processing.blur_ksize / morph_kernel / open_iterations / close_iterations | 5 / 5 / 1 / 2 |
| 최소 면적 | selection.min_area | auto = 0.3 × (1 m에서 30×30 mm 면의 화면 넓이). fx 454.1 → 55 px (뎁스 없을 때) |
| depth | depth.min_area_px | 80 px (뎁스 있을 때. 실측 1 m 최소 211 px) |
| depth | depth.no_depth_min_area | 800 px (너무 가까워 뎁스가 0일 때 색만으로 믿을 최소 면적) |
| 최대 면적 | selection.max_area_ratio | auto → 0.6 (화면의 60% 초과는 배경) |
| 모양 | selection.max_aspect / min_extent / min_solidity | 3.0 / 0.35 / 0.5 |
| 거리·크기 | depth.min_m / max_m, max_short_m / max_long_m, area_m2 | 0.1~1.1 m, 짧은 변 ≤ 5 cm, 긴 변 ≤ 8 cm, 3~30 cm² |
| 카메라 | camera.exposure / white_balance / options | 노출 자동, 화이트밸런스 4600 K 고정, auto_exposure_priority: 1 |

4. 원본 위에 컨투어·목표 중심·영상 중심을 표시
   detect()는 상태를 저장하지 않고 매 프레임 독립적으로 판단.
   통과 후보가 없으면 Detection(detected=False)를 반환하고 중심·오차·면적비·bbox를 모두 None으로 둔다.

| 표시 | 의미 |
| --- | --- |
| 초록 굵은 선 | 선택된 목표의 컨투어 |
| 노랑 / 회색 가는 선 | 통과했지만 선택되지 않은 후보 / 탈락 후보 |
| 빨간 점 | 목표 중심 (빨간 선 = 영상 중심에서 목표 중심까지) |
| 흰 십자 | 영상 중심 (W/2, H/2) |
| 윗줄 | DETECTED c=(원본 좌표) ex ey area n 또는 NO TARGET center=None ex=None ey=None |
| 둘째 줄 | 뎁스 Z=…m size=…cm (실제 거리·크기 추정) |

5. 목표가 잘 보이는 장면·없는 장면·일부 가려진 장면을 같은 설정으로 확인
   같은 설정 파일(config_used.yaml)로 처리. 가림 장면은 보이는 부분(1.5 × 2.7 cm)만으로 검출했고, 면적 하한을 느슨하게 설정. 마스크의 작은 점은 too_small로 탈락. 같은 원본·뎁스를 최종 설정으로 다시 처리해 캡쳐이미지를 만들었다.
   
| 장면 | 원본 | 마스크 | 검출 |
| ----- | --- | --- | --- |
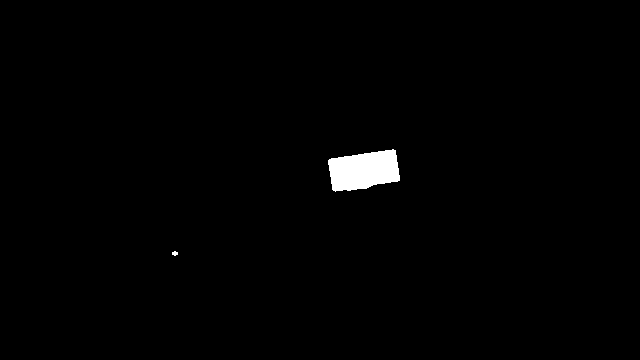
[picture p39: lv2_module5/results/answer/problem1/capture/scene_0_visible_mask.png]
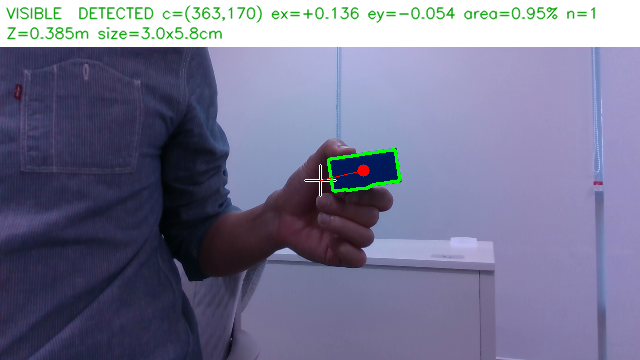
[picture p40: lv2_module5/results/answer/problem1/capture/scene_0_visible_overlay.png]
| 잘 보임  |   |   |   |
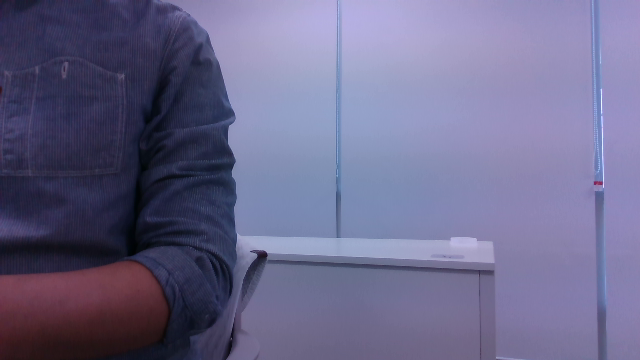
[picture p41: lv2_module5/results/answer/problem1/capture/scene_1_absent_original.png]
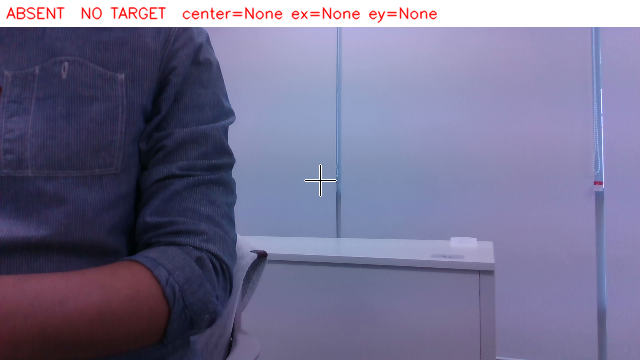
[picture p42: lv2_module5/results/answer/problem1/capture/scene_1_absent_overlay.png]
| 없음 |  |  |  |
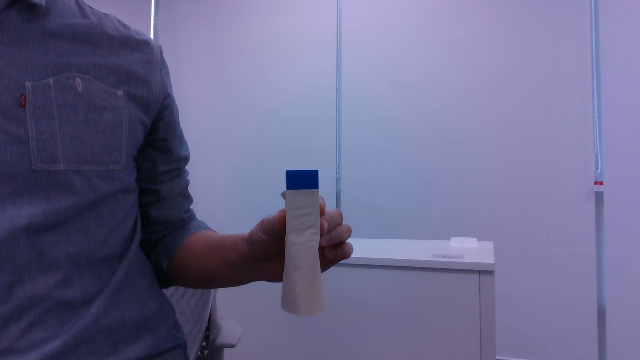
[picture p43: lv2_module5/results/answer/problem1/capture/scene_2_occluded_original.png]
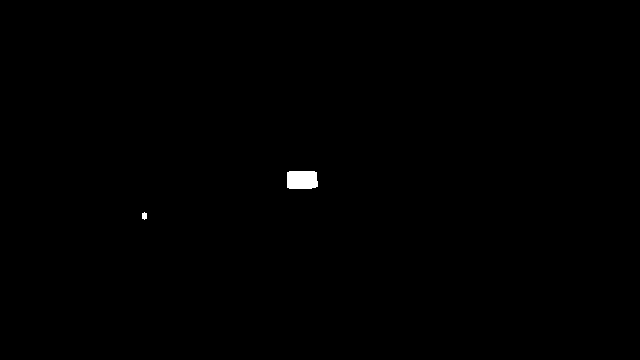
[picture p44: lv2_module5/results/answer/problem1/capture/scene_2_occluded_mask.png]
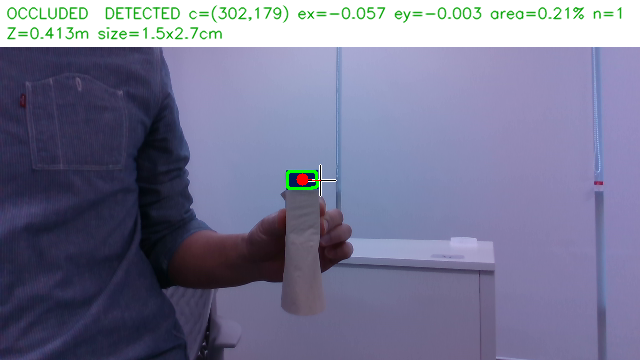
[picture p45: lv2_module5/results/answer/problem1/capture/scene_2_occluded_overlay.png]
| 일부 가림 |  |  |  |

HSV 범위를 정한 근거

S 하한을 바꿔 가며 전체 데이터로 평가하면, 170~230에서만 인식 100%·오검출 0%. → 가운데 200.
H는 96~130 어디서나 통과 → 큐브 H 112를 가운데로 104~120.
V 하한은 8~38 모두 통과 → 이번 데이터보다 더 어두운 환경을 위해 8(더 낮은 밝기는 색 세기 하한 5로 잡음을 거른다).
처음 범위(`[103,208,26]~[116,…]`)는 큐브 앞면 8×12 px만 보고 정한 값이었다. 이후 조명별로 측정한 값으로 적용.

| | 큐브 (p2 ~ p98) | 배경 중 H 100~125 픽셀 |
| --- | --- | --- |
| H | 110 ~ 113 | 넓게 분포 (배경 전체 중앙값 122~128) |
| S | 248 ~ 255 | 중앙값 69~83, 상위 1% 124~163  |
| V | 38~46 (어두움), 84~103 (보통·밝음) | 중앙값 120~138 |

배경 오검출을 줄인 조건

| 조건 | 설정 | 효과(근거) |
| --- | --- | --- |
| 채도 하한 S ≥ 200 | hsv_ranges | 배경의 옅은 파랑(의자·카펫·데님) 제외. 배경 파란 계열의 99%가 S < 163 |
| 완화 범위 제거 | relaxed_ranges 없음 | 이전에는 "진한 파랑과 붙은 S ≥ 80 픽셀"도 인정했는데, 의자·카펫(S 80~125)이 큐브에 붙어 덩어리가 커졌다. 제거 후 뎁스 없이 판단해도 큐브 없는 장면 오검출 75% → 0% |
| 색 세기 하한 | min_chroma: 5 | 어두운 픽셀은 잡음만으로 S가 커지므로 max−min이 작은 픽셀 제외 |
| 열림·닫힘 | 5×5, 1회·2회 | 점 잡음 제거, 큐브 내부 구멍 메움 |
| 최소·최대 면적 | 55 px(뎁스 없음)·80 px(뎁스), 화면 60% | 작은 조각·화면 전체 배경 제외 |
| 모양 | 장변/단변 ≤ 3, 채움비 ≥ 0.35, solidity ≥ 0.5 | 줄무늬·막대·구불구불한 덩어리 제외(뎁스 유무와 상관없이 항상 적용) |
| 뎁스 거리 | 0.1~1.1 m | 뒤쪽 멀리 있는 같은 색 물체 제외 |
| 뎁스 실제 크기 | 짧은 변 ≤ 5 cm, 긴 변 ≤ 8 cm, 3~30 cm² | 같은 색이지만 크기가 다른 물체(카드·셔츠) 제외. 실측 큐브: 2.0~3.1 × 5.4~6.2 cm, 10.7~17.8 cm² |

미검출 전달 방식

| 위치 | 미검출 표현 |
| --- | --- |
| detect() 반환 | detected=False, center·center_original·error·area_ratio·bbox = None |
| 기록 JSON | 위 값이 `null` (scene_1_absent.json) |
| 화면 | NO TARGET center=None ex=None ey=None, 목표 중심(빨간 점)을 그리지 않음 |
| ROS /target (detector_node.py) | 정상 영상의 미검출은 point.z = 0(x·y = 0)으로 매 영상마다 발행. 받는 쪽은 z = 0이면 x·y로 제어하지 않는다 |
| 카메라 정지 | 새 영상이 0.3 s 없으면 /target을 발행하지 않고 /perception_status = CAMERA_STALL — 미검출(z=0)과 통신 중단을 구분 |

조명·거리 변화에 따른 검출률·처리 속도

같은 데이터(조건당 100장)를 최종 설정과 최적화 전 설정으로 처리했다.
처리 시간 = 해상도 맞춤 ~ 중심 계산(색·모양·뎁스 검증 포함), 화면 표시·카메라 대기 제외. 

조명 변화 (거리 약 0.5 m 고정)

| 조명  | 최종: 검출률 | 최종: 처리 ms (평균/p95) | 최적화 전: 검출률 | 최적화 전: 처리 ms |
| --- | --- | --- | --- | --- |
| 어두움 | 100% | 1.03 / 1.26 | 0% | 7.58 / 9.36  |
| 보통  | 100% | 0.96 / 1.15 | 100% | 6.07 / 6.62  |
| 밝음  | 100% | 0.97 / 1.12 | 100% | 2.84 / 3.03  |

거리 변화 (보통 조명, 1.0 m는 어두움·밝음)

| 거리(실측 Z) | 최종: 검출률 | 최종: 처리 ms | 최적화 전: 검출률 | 최적화 전: 처리 ms |
| --- | --- | --- | --- | --- |
| 0.1 m (0.16 m) | 100% | 1.03 / 1.18 | 100% | 3.19 / 3.36  |
| 0.2 m (0.32 m) | 100% | 1.03 / 1.17 | 100% | 6.05 / 6.52  |
| 0.5 m (0.55 m) | 100% | 0.96 / 1.15 | 100% | 6.07 / 6.62  |
| 1.0 m 어두움 (1.02 m) | 100% | 1.28 / 1.46 | 0% | 7.04 / 8.82  |
| 1.0 m 밝음 (1.02 m)  | 100% | 0.96 / 1.11 | 3% | 5.42 / 5.90  |

평균 처리 5.3 → 1.0 ms.
어두울수록 검출률이 떨어졌다(0%). 어두운 배경의 옅은 파랑이 완화 범위로 큐브에 붙어 실제 크기가 12~77 cm로 계산돼 size_mismatch로 탈락했다. 밝음 0.2 m·1.0 m도 같은 이유(짧은 변 5.2~6.0 cm).
처리 시간도 덩어리가 클수록 늘었다(뎁스 분할 시도 포함 최대 9.4 ms). 최종 설정은 마스크가 큐브만 남아 조건과 상관없이 약 1 ms로 일정하다.
거리에 따른 차이는 작다: 1 m에서도 큐브는 최소 211 px로 최소 면적(80 px)보다 크고, 뎁스는 0.15~1.03 m 전 구간에서 99~100% 측정됐다(실측 크기 2.0~3.1 × 5.4~6.2 cm).
실시간 처리 속도의 한계는 검출이 아니라 카메라: tuning bench(어두움 1.0 m, 실제 카메라, 100프레임) 프레임 대기 26.4 ms( 30 fps) 대비 검출 처리 1 ms.

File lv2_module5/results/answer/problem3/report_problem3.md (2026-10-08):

# 문제 3 — 중심 기반 추적 제어

실험 장비: 
- Raspberry Pi (Ubuntu 26.04, ROS 2 Lyrical)
- RealSense D435 + OpenCR(V3 펌웨어)
- Dynamixel 팬(ID11)·틸트(ID12)

## 1. 구성

문제 3 구성 · 인지 → 제어 → 구동

*문제 3 구성 · 인지 → 제어 → 구동*

| 단계 | 노드 | 역할 |
|---|---|---|
| 인지 | `target_detector` | HSV·컨투어·뎁스 검증으로 퍽 검출, 화면 중심 오차 ex·ey ∈ [-1, 1] 발행 (약 30 Hz) |
| 제어 | `tracking_controller` | 오차 → 팬·틸트 각속도 명령, 상태(WAITING·TRACKING·CENTERED·LOST·TIMEOUT) 발행 (20 Hz) |
| 구동 | `control` | `/cmd_vel` → OpenCR 속도 명령, 펌웨어 상태 → `/joint_states` |

실행 (보드):

```bash
ros2 run xmen_control control --ros-args -p port:=/dev/ttyACM0   # 구동, 시작 시 홈 복귀
ros2 launch target_bringup bringup.launch.py                       # detector + controller (+ motor_driver 출력 OFF, 로그만)
```

| 패키지 (보드 경로) | 실행 파일 | 설정 |
|---|---|---|
| `xmen_vision/target_perception` | `detector` — pyrealsense2로 카메라 직접(`source:=realsense`), 640×360@30 | `config/detector.yaml` |
| `xmen_control/target_control` | `controller`, `motor_driver` | `xmen_bringup/target_bringup/config/tracking.yaml` |
| `xmen_control` (제어 담당) | `control` — V3 펌웨어 `v <팬> <틸트>` [rad/s] | 파라미터 `port`, `auto_home` |

## 2. 방향·부호 확인

추적을 끄고(controller 미실행) control만 켠 상태에서 작은 명령(0.1 rad/s)을 축마다 보내 실제 회전 방향을 확인했다.

```bash
ros2 topic pub -r 20 /cmd_vel geometry_msgs/msg/Twist "{angular: {z: 0.1}}"   # 팬
ros2 topic pub -r 20 /cmd_vel geometry_msgs/msg/Twist "{angular: {y: 0.1}}"   # 틸트
```

| 축 | `/cmd_vel` + 명령 시 실제 방향 | 오차 정의 | 결정한 direction |
|---|---|---|---|
| 팬 (angular.z) | 왼쪽 | ex > 0 = 목표가 오른쪽 → 오른쪽(음수)으로 회전 | `cmd_sign = -1` |
| 틸트 (angular.y) | 위 | ey > 0 = 목표가 아래 → 아래(음수)로 회전 | `cmd_sign_tilt = -1` |

control은 `/cmd_vel`을 부호 변환 없이 펌웨어로 전달한다(`pan, tilt = angular.z, angular.y`). 부호는 controller의 `cmd_sign`·`cmd_sign_tilt` 한 곳에서만 정한다.

부호 결정 기준: 목표를 오른쪽·아래에 두었을 때 카메라가 그쪽으로 돌아 오차가 줄어드는지로 판단했다.
첫 시험(`cmd_sign_tilt = 1`)에서는 목표가 화면 아래(ey ≈ +0.9)에 있을 때 틸트 명령이 +0.4(위)로 나가 목표가 화면 아래로 빠졌고, LOST↔TRACKING이 반복됐다. `cmd_sign_tilt = -1`로 바꾼 뒤 해소됐다.
시험 중 control.py에 틸트 반전(`-angular.y`)이 임시로 들어가 부호가 두 번 뒤집힌 적이 있어, 반전은 제거하고 controller 한 곳에서만 부호를 정하기로 했다.

## 3. 제어식과 설정

속도형 P 제어 (축마다 독립):

```
command = 0                                                  (|e| < deadband)
command = clamp(direction × Kp × e, -speed_limit, +speed_limit)   (그 외)
```

| 항목 | 팬 | 틸트 | 단위·비고 |
|---|---|---|---|
| Kp | 1.5 / 2.0 / 2.5 / 4.5 (비교 대상) | 0.8 (고정) | [rad/s] per 정규화 오차 1.0. ex = 1 ≈ 화각 절반(팬 약 35°, 틸트 약 21°) |
| direction | -1 | -1 | 2절 |
| speed_limit | 0.6 | 0.4 | rad/s |
| deadband | 0.05 | 0.05 | 정규화 오차 |
| 명령 주기 | 20 Hz 타이머 | | 각속도 명령이라 controller에서 적분하지 않음(dt 사용 없음). 위치 변화는 펌웨어·모터 프로파일이 만든다 |
| 입력 타임아웃 | 0.5 s | | 신선한 `/target`이 없으면 TIMEOUT, 정지 명령. 촬영 시각이 0.5 s보다 오래된 입력도 거부 |
| 미검출 | z = 0 → LOST, 정지 명령 | | 이전 속도 유지 안 함 |

회전 범위·정지 (펌웨어, 제어 담당):
- 범위: 팬 ±180°, 틸트 ±135° (홈 기준). 범위 끝에서 감속 후 위치 유지. 바깥 방향 명령 차단 여부 (확인 필요)
- 속도 명령이 500 ms 동안 갱신되지 않으면 펌웨어가 스스로 정지, control은 0.5 s 무명령 시 `v 0 0` 전송
- 속도 명령은 "범위 끝을 목표로 한 프로파일 속도 이동"으로 구현되어 있고 가속 시간 0.3 s

Kp 1.5 추적
- kp1.5 

<br>

Kp 2.0 추적
- kp2.0 

<br>

Kp 2.5 추적
- kp2.5 

<br>

## 4. 시험 방법

- 시나리오: 왼쪽 3초 정지 → 중앙 3초 → 오른쪽 3초 → 중앙 3초. 바닥에 위치 표시를 붙여 반복 조건을 맞췄다.
- 회차 시작 전 원점 복귀: `ros2 topic pub --once /opencr/home std_msgs/msg/Empty '{}'`
- Kp 4종 × 3회, 회차마다 rosbag 기록: `/target /cmd_vel /tracking_status /joint_states /perception_status`
- 분석(PC): bag 재생 → `track_logger`로 CSV 변환 → `track_plot`으로 요약. 파라미터 값은 보드 `tracking.yaml`에서 kp만 바꿔 bringup을 재시작했다(나머지 고정)
- 실제 Kp는 CSV의 명령/오차 비로 역산해 12회 모두 설정값과 일치함을 확인했다.
- 수평 RMSE = sqrt(mean(ex²)), 검출되고 상태가 TRACKING·CENTERED인 프레임만 사용. CENTERED는 오차가 데드밴드 안이라 명령이 0인 추적 상태이므로 추적 구간에 포함했다. 사용·제외 프레임 수를 함께 적는다.
- 포화 비율 = |ex| > 0.06(데드밴드 밖)일 때의 명령 중 |명령| ≥ 0.59 rad/s(상한 0.6)인 비율.

달라진 조건:
- run1은 다른 세션에서 먼저 기록했다(bag 녹화 시각: kp4.5 18:19, kp2.5 18:28, kp1.5 19:20, kp2.0 19:26 / run2·3은 모두 19:39~19:46). 기록 길이도 31~42 s로 run2·3(18~24 s)보다 길고, 포화 비율이 3~10%(kp4.5 제외)로 낮다. 퍽을 더 천천히 옮기는 등 조건이 달랐던 것으로 보여 같은 조건 비교(5절 run2·3 열, 6절)에서 제외하고 참고값으로만 둔다.
- 그 결과 같은 조건 회차는 Kp마다 2회다. 발제의 "Kp별 3회"는 run1을 포함해야 채워지므로, 3회 값은 조건 차이를 밝힌 참고값으로 함께 적는다. 단, 흔들림 지표(5절)는 run1을 넣어도 빼도 결론이 같다.
- kp2.0_run2는 검출 비율 76.8%로 135프레임이 제외됐다. (원인 확인 필요)
- 조명·거리·목표 이동 담당자 (확인 필요)

## 5. 결과

### 회차별

| 회차 | 길이 [s] | 처리 FPS | 검출 출력 비율 | 사용 / 제외 | RMSE ex | RMSE ey | 최대 \|ex\| | 포화 비율 |
|---|---|---|---|---|---|---|---|---|
| kp1.5_run1 | 35.4 | 29.9 | 0.882 | 907 / 152 | 0.202 | 0.097 | 0.966 | 0.03 |
| kp1.5_run2 | 19.6 | 29.6 | 1.000 | 581 / 0 | 0.264 | 0.077 | 0.522 | 0.32 |
| kp1.5_run3 | 18.5 | 30.0 | 0.998 | 552 / 2 | 0.317 | 0.079 | 0.623 | 0.37 |
| kp2.0_run1 | 31.3 | 30.0 | 0.989 | 927 / 13 | 0.172 | 0.088 | 0.540 | 0.10 |
| kp2.0_run2 | 18.2 | 30.0 | 0.768 | 412 / 135 | 0.395 | 0.085 | 0.842 | 0.62 |
| kp2.0_run3 | 20.5 | 30.0 | 0.998 | 611 / 4 | 0.295 | 0.076 | 0.948 | 0.41 |
| kp2.5_run1 | 42.1 | 30.0 | 1.000 | 1261 / 1 | 0.116 | 0.101 | 0.326 | 0.09 |
| kp2.5_run2 | 21.3 | 30.0 | 1.000 | 639 / 0 | 0.332 | 0.068 | 0.882 | 0.51 |
| kp2.5_run3 | 18.1 | 30.0 | 1.000 | 541 / 1 | 0.353 | 0.075 | 0.785 | 0.69 |
| kp4.5_run1 | 42.5 | 30.0 | 0.471 | 590 / 684 | 0.124 | 0.149 | 0.475 | 0.44 |
| kp4.5_run2 | 21.3 | 30.0 | 1.000 | 639 / 0 | 0.280 | 0.058 | 0.861 | 0.67 |
| kp4.5_run3 | 23.9 | 30.0 | 1.000 | 715 / 2 | 0.350 | 0.056 | 0.913 | 0.75 |

검출 출력 비율은 `/target`의 z > 0 비율이다(목표가 항상 화면 안에 있다는 가정). 사람이 영상과 대조하는 문제 4의 검출률과는 다르다. 처리 FPS는 `/target` 수 / 경과 시간이며 카메라 설정은 30 fps.

### Kp별 평균

같은 조건(run2·3) 기준. 3회 평균 열은 조건이 다른 run1을 포함한 참고값이다.

| Kp | run2·3 RMSE ex (각 회차) | run2·3 평균 | run2·3 검출 출력 비율 | run2·3 포화 비율 | 참고: run1 포함 3회 평균 ± 표준편차 |
|---|---|---|---|---|---|
| 1.5 | 0.264, 0.317 | 0.291 | 0.999 | 0.35 | 0.261 ± 0.058 |
| 2.0 | 0.395, 0.295 | 0.345 | 0.883 | 0.51 | 0.288 ± 0.112 |
| 2.5 | 0.332, 0.353 | 0.342 | 1.000 | 0.60 | 0.267 ± 0.131 |
| 4.5 | 0.280, 0.350 | 0.315 | 1.000 | 0.71 | 0.252 ± 0.116 |

그래프: Kp별 대표 회차(run2)의 시간–ex·ey, 시간–명령, 시간–실제 각도(`/joint_states`). 배경색은 상태 구간. 
명령과 실제 각도는 서로 다른 그래프에 그린다. 실제 각도는 약 2 Hz로만 측정되어 점으로 표시한다.

### 흔들림 (진동) 비교

같은 CSV에서 흔들림을 따로 계산했다.
- 부호 반전 = 검출 프레임의 ex가 데드밴드(±0.05) 밖에서 부호를 바꾼 횟수 / 10 s. 0.05 이내 프레임은 건너뛴다. 팬 명령의 부호 반전 횟수와 12회 모두 같았다.
- 중심 근처 RMS = |ex| < 0.3 프레임만으로 계산한 sqrt(mean(ex²)). 이동 직후의 포화 구간을 뺀 값이다.

| Kp | 부호 반전 / 10 s (run1, run2, run3) | 3회 평균 | run2·3 평균 | 중심 근처 RMS (run1, run2, run3) |
|---|---|---|---|---|
| 1.5 | 2.3, 3.6, 2.7 | 2.9 | 3.1 | 0.161, 0.132, 0.146 |
| 2.0 | 1.9, 2.4, 2.4 | 2.3 | 2.4 | 0.142, 0.111, 0.132 |
| 2.5 | 1.9, 3.3, 2.8 | 2.7 | 3.0 | 0.113, 0.125, 0.110 |
| 4.5 | 4.3, 7.0, 6.7 | 6.0 | 6.9 | 0.096, 0.128, 0.118 |

시나리오상 목표가 중심을 지나는 이동이 있어 Kp와 상관없이 일정 횟수의 반전은 생긴다. Kp 간 비교는 이 기본값보다 얼마나 많은지로 본다.

Kp 1.5 run2

*Kp 1.5 run2 — 위: ex·ey, 가운데: 팬·틸트 명령, 아래: `/joint_states` 실제 각도(약 2 Hz). 이동 구간에서만 0.6 rad/s 포화, 중심 근처에서는 반전이 작다*

Kp 4.5 run2

*Kp 4.5 run2 — 같은 구성. 2~5 s, 15~17 s, 20~22 s에 ex가 ±0.15~0.2로 중심을 오가고 팬 명령이 +0.6 ↔ −0.6으로 번갈아 나간다(부호 반전 7.0회 / 10 s)*

## 6. 해석

1. 같은 조건(run2·3)에서 Kp별 평균 RMSE ex는 0.291~0.345로 차이가 약 0.05인데, 같은 Kp 안의 회차 간 차이는 최대 0.10(Kp 2.0: 0.295 vs 0.395)으로 더 크다. 이 범위의 Kp로는 성능 차이를 구분할 수 없다.
2. 원인은 속도 포화다. Kp = 1.5에서도 |ex| ≥ 0.4면 명령이 0.6 rad/s에 걸린다. 시나리오가 목표를 ±0.5 이상 한 번에 옮기므로 이동 직후에는 Kp와 관계없이 최대 속도로 회전하고, 오차 감소 속도는 speed_limit이 결정한다. Kp가 커질수록 포화 비율이 0.35 → 0.71로 늘었다.
3. (조건이 다른 run1, 참고) Kp = 4.5_run1은 검출 출력 비율 47%, 제외 684프레임으로, 중심을 지나쳐 목표를 화면 밖으로 놓친 구간이 길었다. RMSE(0.124)가 낮게 나온 것은 놓친 프레임이 계산에서 빠졌기 때문이므로 좋은 결과로 해석하지 않는다.
4. Kp = 1.5는 run2·3 기준 포화 비율과 최대 |ex|가 가장 낮고 검출이 안정적이었다. 흔들림(부호 반전)은 1.5~2.5 사이에서 차이가 없어(run2·3 평균 2.4~3.1회) 선택 근거로 쓰지 않았다. 현재 speed_limit 0.6 rad/s에서는 Kp 1.5~2.5 범위가 적절하고, 4.5는 놓침 위험이 있다.
5. 응답 지연 요인: 카메라 → 검출 → controller(20 Hz) → control(최대 20 Hz 전송) → 펌웨어(가속 0.3 s). 정지 시에는 데드밴드 경계(|ex| ≈ 0.05 → 0.05 × 35° ≈ 1.8°)에서 멈춘다.
6. RMSE와 달리 흔들림은 Kp에 따라 갈린다. 같은 조건(run2·3)에서 Kp = 4.5의 부호 반전은 10 s당 6.7~7.0회로, 다른 Kp(2.4~3.6회)의 약 2배다. 조건이 다른 run1을 넣어도 4.5(4.3회)가 다른 Kp의 최댓값(3.6회)보다 많아 결론은 같다. 그래프에서도 4.5는 중심 근처에서 ±0.6 rad/s 명령이 좌우로 번갈아 나가는 진동이 보인다. 중심 근처 RMS는 0.10~0.16으로 Kp마다 뚜렷한 차이가 없어(4.5 run1의 0.096이 가장 낮지만 run2·3은 0.118~0.128), Kp를 올려도 중심 오차는 줄지 않고 흔들림만 늘었다.

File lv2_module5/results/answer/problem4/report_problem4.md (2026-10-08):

# 문제 4 — 성능 측정과 소실 복구

## 1. 상태와 동작

| 발제 상태 | 구현 상태 (`/tracking_status`) | 조건 | 동작 |
|---|---|---|---|
| IDLE | `WAITING` | 시작 후 신선한 입력을 아직 받지 못함 | 정지 명령 |
| IDLE | `IDLE` | `/tracking_enable` = false (명시적 중지) | 정지 명령. true가 되면 복귀 절차부터 |
| TRACKING | `TRACKING` / `CENTERED` | 신선한 입력에서 검출(z > 0). CENTERED는 두 축 모두 데드밴드 안 | 속도 상한·데드밴드 안에서 P 제어 / 정지 |
| LOST | `LOST` | 신선한 입력에서 미검출(z = 0) | **미검출 첫 프레임부터** 정지 명령. 이전 속도·좌표 사용 안 함 (표시 유예 없음) |
| LOST | `TIMEOUT` | 마지막 신선한 입력 후 0.5 s 경과, 또는 촬영 시각이 0.5 s보다 오래됨 | 정지 명령 |
| 복귀 | `LOST` → `TRACKING` | 신선한 입력에서 **연속 3프레임** 검출(`recover_frames: 3`, 30 fps ≈ 0.1 s). 중간에 미검출이 끼면 처음부터 셈 | 그동안 LOST 유지·정지, 3프레임 뒤 같은 P 제어(속도 상한 적용)로 재개 |

정지 보장 (구동 쪽, 제어 담당):
- control: `/cmd_vel`이 0.5 s 동안 없으면 `v 0 0` 전송
- OpenCR V3 펌웨어: 속도 명령이 500 ms 동안 갱신되지 않으면 스스로 정지 (control 프로세스가 죽어도 동작)
- 속도 명령은 위치 목표로 구현되어 있으나, 정지는 "목표 갱신 중단"이 아니라 펌웨어가 현재 위치를 목표로 다시 쓰는 방식이다. 실제 정지는 3.4절 제어 통신 중단 시험으로 확인한다.

시야 밖 탐색은 하지 않았다. 기본 복구 = 시야 안 재등장 재검출.

설정: Kp = 1.5 (문제 3에서 RMSE·포화 비율이 가장 낮았던 값), Kp_tilt 0.8, 속도 상한 0.6 / 0.4 rad/s, 데드밴드 0.05, 명령 20 Hz, 입력 타임아웃 0.5 s.

## 2. 시험 방법

| 시험 | bag | 방법 |
|---|---|---|
| 정상 추적 | `p4_normal` | 30 s 이상 퍽을 움직이며 추적 |
| 가림 후 재등장 | `p4_occl` | 추적 중 손으로 약 2 s 가렸다가 치우기 5회 |
| 인지 입력 중단 | `p4_input` | 추적 중 `pkill -f target_perception/detector` |
| 제어 통신 중단 | `p4_ctrl` | 모터가 회전하는 중 `pkill -9 -f xmen_control/control`, 모터 정지를 영상으로 확인 |

기록 토픽: `/target /cmd_vel /tracking_status /joint_states /perception_status`.
분석(PC): bag 재생 → `track_logger` CSV → `track_recovery`(이벤트·복구 시간) · `track_plot`(FPS·RMSE).

이벤트 판정 (`track_recovery`):
- 소실 시각 = 상태가 TRACKING·CENTERED → LOST·TIMEOUT으로 바뀐 시각
- 정지 = 그 뒤 첫 `/cmd_vel`이 팬·틸트 모두 0
- 재등장 시각 = 그 뒤 처음 검출된 `/target`
- 복귀 시각 = 재등장 뒤 처음 TRACKING·CENTERED
- 복구 시간 = 복귀 − 재등장, 3 s 이내면 성공

## 3. 결과

### 3.1 정상 추적 (`p4_normal`, 42.5 s)
정상 추적

| 지표 | 값 | 비고 |
|---|---|---|
| 처리 FPS | 29.98 | `/target` 수 / 경과 시간. 카메라 설정 30 fps |
| 검출 출력 비율 | 76.4% (1274프레임 중 z > 0) | 사람 대조 검출률은 4절 |
| 수평 RMSE (ex) | 0.247 | 추적 구간 938프레임 사용, 336프레임 제외. 추적 구간 비율 73.6% (938 / 1274), 검출 프레임 중 TRACKING 96.4% (938 / 973) |
| 수직 RMSE (ey) | 0.407 | |
| 최대 \|ex\| | 0.953 | |
| 소실 | 11회, 그중 10회 복구 (0.07~0.32 s) | 마지막 1회는 녹화 종료로 판정 불가 |

정상 추적 그래프

*정상 추적 — 위: ex·ey(× = 미검출), 가운데: 팬·틸트 명령, 아래: `/joint_states` 실제 각도(약 2 Hz). 배경색은 상태(파랑 TRACKING, 분홍 LOST). 15 s 이후 ey가 ±0.5~0.85까지 커지고 틸트 명령이 ±0.4 rad/s 상한에 자주 걸린다*

### 3.2 가림 후 재등장 (`p4_occl`)
가림 후 재등장

| 회 | 소실 [s] | 정지까지 [s] | 재등장 [s] | 가림 시간 [s] | 복귀 [s] | 복구 시간 [s] | 판정 |
|---|---|---|---|---|---|---|---|
| 1 | 10.614 | 0.050 | 12.561 | 1.95 | 12.663 | 0.102 | 성공 |
| 2 | 17.114 | 0.049 | 20.899 | 3.79 | 21.015 | 0.116 | 성공 |
| 3 | 25.417 | 0.046 | 29.135 | 3.72 | 29.215 | 0.080 | 성공 |
| 4 | 33.263 | 0.051 | 35.668 | 2.41 | 35.767 | 0.099 | 성공 |
| 5 | 40.812 | 0.051 | 42.540 | 1.73 | 42.664 | 0.124 | 성공 |

- **복구 성공률 5 / 5 = 100%**, 복구 시간 평균 0.104 s (0.080~0.124 s)
- 5회 모두 소실 후 다음 명령 주기(≤ 0.05 s) 안에 정지 명령
- 복구 시간 ≈ 연속 3프레임(0.1 s) + 명령 주기. 복귀 조건이 의도대로 동작함
- 의도하지 않은 소실 2회(47.8 s: 0.11 s 만에 복구 / 48.8 s: 녹화 종료로 재등장 미기록)는 가림 시험 통계에서 제외하고 여기 기록한다
- 2·3회차는 가림 시간이 3.7~3.8 s로 발제 조건(약 2 s)보다 길었다. 복구 판정(재등장 후 3 s 이내)에는 영향이 없다.

가림 후 재등장 그래프

*가림 후 재등장 — 분홍(LOST) 구간마다 팬·틸트 명령이 0으로 떨어지고 실제 각도가 평평하게 유지된다. 시작 0~7 s의 LOST는 시험 시작 전(목표를 아직 보여주지 않음)이다*

### 3.3 인지 입력 중단 (`p4_input`)
인지 입력 중단

| 마지막 입력 [s] | TIMEOUT [s] | 타임아웃까지 [s] | 정지 명령 |
|---|---|---|---|
| 13.155 | 13.696 | 0.541 | 다음 주기(0.050 s) 안에 0 |

설정 0.5 s + 명령 주기(0.05 s) 안에서 TIMEOUT으로 바뀌고 정지 명령을 냈다. 이후 controller가 재시작될 때(56.2 s, WAITING)까지 약 42.5 s 동안 /cmd_vel 594개가 모두 0이었다.

인지 입력 중단 그래프

*인지 입력 중단 — 13.7 s부터 TIMEOUT(진한 분홍), 명령은 0으로 유지되고 실제 각도도 팬 0.75 rad·틸트 0.21 rad에서 멈춰 있다. 48~50 s에 각도가 0으로 움직인 것은 명령이 0인 동안이므로 `/cmd_vel`에 의한 것이 아니다*

### 3.4 제어 통신 중단 (`p4_ctrl`)
제어 통신 중단

| 항목 | 값 |
|---|---|
| control 종료 시각 | 약 22.1 s (마지막 `/joint_states` 22.09 s) |
| 종료 직전 회전 | 팬 0.68 → 0.53 rad(약 −0.28 rad/s), 틸트 0.23 → 0.11 rad(약 −0.24 rad/s). 21.55~22.09 s `/joint_states` 기준으로 회전 중에 종료함 |
| 종료 후 tracker 명령 | 27.07 s까지 0이 아닌 명령이 계속 나감(틸트 −0.4 rad/s 포화). tracker는 control 종료를 알지 못하므로 정지는 펌웨어 워치독에만 의존 |
| 모터 정지 (간접) | 24.8~27.1 s에 틸트 −0.4 rad/s 포화 명령이 나가는데도 ey가 0.55~0.79에서 변하지 않음 → 카메라가 명령에 반응하지 않음 = 정지로 판단. 목표를 고정해 두었다는 가정이 필요하고, 정지 시점(500 ms 이내인지)은 bag으로 알 수 없음 |
| 재기동 후 위치 | 측정 안 함 — bag에 control 재시작 구간이 없음 |

control이 죽으면 `/joint_states`도 끊기므로 bag만으로는 정지를 증명할 수 없다. 정지 판정은 영상으로 한다.
종료 전 추적 중 짧은 소실 5회(0.07~0.12 s 만에 복구)는 이 시험의 판정 대상이 아니다.

제어 통신 중단 그래프

*제어 통신 중단 — 아래 그래프의 실제 각도가 22.1 s에서 끊긴다(control 종료). 가운데 그래프에서 그 뒤에도 tracker 명령은 계속 나가고, 25 s 이후 틸트 −0.4 rad/s 포화 명령에도 위 그래프의 ey가 거의 변하지 않는다*

## 4. 검출률·배경 오검출 (사람 대조)

| 지표 | 계산 | 조건 | 결과 |
|---|---|---|---|
| 검출률 | 올바른 검출 / 목표가 보이는 장 × 100 | `frames/p4_normal2` 100장 | 검출기 출력 기준 95 / 100 = 95%. 미검출 5장은 모두 목표가 보이는데 놓친 것으로 확인. 검출 95장의 정답 대조 |
| 배경 오검출 | 목표가 없는 장 중 검출(`_1`)된 수 | `frames/p4_empty` 105장 | 검출기 출력 기준 0 / 105. 목표 없음 육안 확인 |

| 검출 | 미검출 (역광) | 미검출 (손 겹침·반사) | 목표 없음 |
|---|---|---|---|
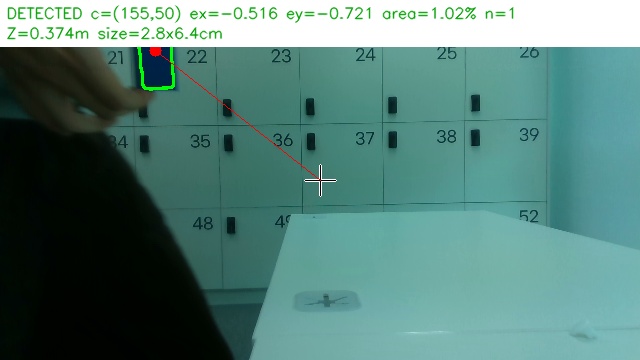
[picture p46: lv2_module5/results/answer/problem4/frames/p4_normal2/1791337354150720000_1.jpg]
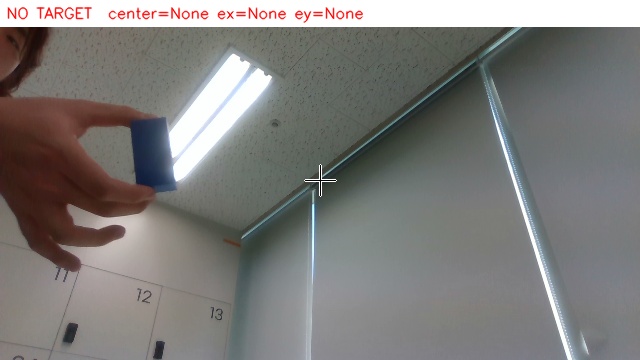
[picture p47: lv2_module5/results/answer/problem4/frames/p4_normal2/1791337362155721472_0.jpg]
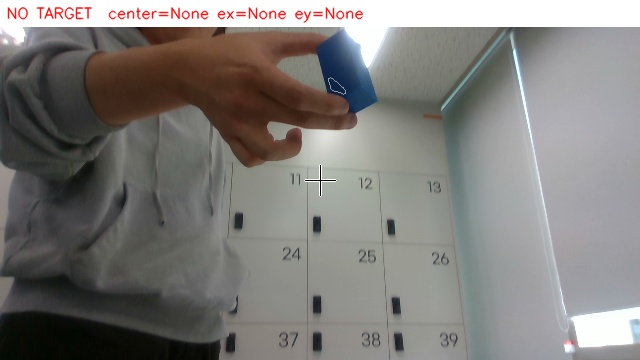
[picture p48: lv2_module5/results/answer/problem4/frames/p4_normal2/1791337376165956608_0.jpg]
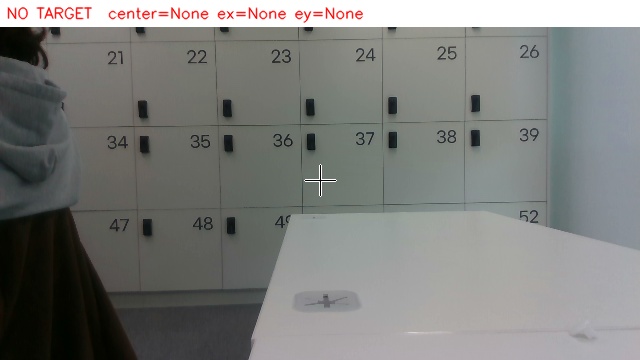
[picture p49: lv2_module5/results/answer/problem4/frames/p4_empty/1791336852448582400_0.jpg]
|  |  |  |  |
| 검출, 거리 0.37 m, 크기 2.8 × 6.4 cm | 형광등 앞에서 목표가 어둡게 찍힘 | 손가락이 목표를 가로지르고 윗면에 하이라이트 | 오검출 없음 |

미검출 5장 중 3장은 카메라가 위를 향해 형광등이 배경에 들어온 역광 장면이고, 2장은 손가락이 목표를 가로지르고 반사 하이라이트가 있는 장면이다.

## 5. 해석

1. 소실 시 정지와 3프레임 복귀는 의도대로 동작했다. 가림 5회 모두 정지했고 0.08~0.12 s 만에 복귀했다(3 s 기준 대비 충분히 짧다).
2. 입력이 끊기면 0.54 s 만에 TIMEOUT·정지로 바뀌어 "이전 속도 유지"가 없다.
3. 정상 추적에서 검출 출력 비율이 76%로 낮고 소실이 11회 있었다. 소실 직전 위치는 12회 중 9회가 |ex| 0.29~0.44로 화면 안쪽이어서, 목표가 화면 밖으로 나간 것이 아니라 검출이 끊긴 것으로 보인다. 나머지 3회(24.8 s ex 0.61, 40.8 s ey 0.95, 41.7 s ex −0.95·ey 0.95)는 목표가 화면 가장자리로 나간 소실이다. 후보 원인: 카메라·목표 이동 중 모션 블러, 조명에 따른 HSV 이탈, 뎁스 검증 탈락. 
4. 수직 RMSE(0.407)가 수평(0.247)보다 크다. 15 s 이후 |ey| > 0.5인 프레임이 252 / 938개이고, 같은 구간(15~41 s) 틸트 명령의 33%가 상한 0.4 rad/s에 포화됐다. 실제 틸트 각도도 −0.62~0.91 rad로 크게 움직였다. 목표를 상하로 크게 옮겨 틸트 속도 상한에 걸린 것으로 보인다.

## 6. 프레임별 기록

발제 권장 컬럼 CSV: `~/bags/csv/track_p4_*_frames.csv`
(`run_id, time_s, frame_id(촬영 시각 ns), detected, ex, ey, area_ratio, state, command, command_tilt, command_unit`)
이벤트 표: `~/bags/csv/recovery_events.csv`

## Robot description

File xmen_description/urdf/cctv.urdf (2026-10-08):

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
<robot name="assembly_1">
    <link name="assembly_2__1_" />
    <link name="dynamixel_xm430_w350_r___Ø_ÄÞ_1__dynamixel_xm430_w350_r___Ø_ÄÞ_1">
        <inertial>
            <mass value="9.39635e-08" />
            <origin xyz="0.011 0.008 0.0109001" rpy="0 -0 0" />
            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
        </inertial>
        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
    </link>
    <link name="dynamixel_xm430_w350_r___Ø_ÄÞ_1__dynamixel_xm430_w350_r___Ø_ÄÞ_1_1">
        <inertial>
            <mass value="9.39635e-08" />
            <origin xyz="0.011 -0.032 0.0109001" rpy="0 -0 0" />
            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
        </inertial>
        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
    </link>
    <link name="dynamixel_xm430_w350_r___Ø_ÄÞ_1__dynamixel_xm430_w350_r___Ø_ÄÞ_1_2">
        <inertial>
            <mass value="2.83728e-08" />
            <origin xyz="0.011 -0.032032 0.0155235" rpy="0 -0 0" />
            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
        </inertial>
        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
    </link>
    <link name="dynamixel_xm430_w350_r___Ø_ÄÞ_1__dynamixel_xm430_w350_r___Ø_ÄÞ_1_3">
        <inertial>
            <mass value="9.39635e-08" />
            <origin xyz="-0.011 -0.032 0.0109001" rpy="0 -0 0" />
            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
        </inertial>
        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
    </link>
    <link name="dynamixel_xm430_w350_r___Ø_ÄÞ_1__dynamixel_xm430_w350_r___Ø_ÄÞ_1_4">
        <inertial>
            <mass value="9.39635e-08" />
            <origin xyz="-0.011 0.008 0.0109001" rpy="0 -0 0" />
            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
        </inertial>
        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
    </link>
    <link name="dynamixel_xm430_w350_r___Ø_ÄÞ_1__dynamixel_xm430_w350_r___Ø_ÄÞ_1_5">
        <inertial>
            <mass value="2.83728e-08" />
            <origin xyz="-0.011 -0.032032 0.0155235" rpy="0 -0 0" />
            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
        </inertial>
        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
    </link>
    <link name="dynamixel_xm430_w350_r__solid_1__dynamixel_xm430_w350_r__solid_1">
        <inertial>
            <mass value="4.28295e-05" />
            <origin xyz="6.41282e-11 -0.0117515 0.00076848" rpy="0 -0 0" />
            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
        </inertial>
        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
    </link>
    <link name="dynamixel_xm430_w350_t__1_" />
    <link name="fr12_h101k">
        <inertial>
            <mass value="0.00800978" />
            <origin xyz="-0.0202538 0.01975 0.000123821" rpy="3.74344e-19 0.00611342 1.14427e-21" />
            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
        </inertial>
        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
    </link>
    <link name="fr12_s102k">
        <inertial>
            <mass value="0.00565134" />
            <origin xyz="-2.09598e-18 -1.11583e-18 -0.0027881" rpy="0 -0 0" />
            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
        </inertial>
        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
    </link>
    <link name="hn12_n101">
        <inertial>
            <mass value="5.8065e-07" />
            <origin xyz="-4.79461e-18 -1.33065e-07 -0.00219311" rpy="0 -0 0" />
            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
        </inertial>
        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
    </link>
    <link name="hn12_n101_1">
        <inertial>
            <mass value="5.8065e-07" />
            <origin xyz="-4.79461e-18 -1.33065e-07 -0.000743106" rpy="0 -0 0" />
            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
        </inertial>
        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
    </link>
    <link name="mate_connector_1">
        <inertial>
            <mass value="1e-09" />
            <origin xyz="0 0 0" rpy="0 -0 0" />
            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
        </inertial>
    </link>
    <link name="mate_connector_1_1">
        <inertial>
            <mass value="1e-09" />
            <origin xyz="0 0 0" rpy="0 -0 0" />
            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
        </inertial>
    </link>
    <link name="mate_connector_4">
        <inertial>
            <mass value="1e-09" />
            <origin xyz="0 0 0" rpy="0 -0 0" />
            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
        </inertial>
    </link>
    <link name="mate_connector_5">
        <inertial>
            <mass value="1e-09" />
            <origin xyz="0 0 0" rpy="0 -0 0" />
            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
        </inertial>
    </link>
    <link name="part_1">
        <inertial>
            <mass value="7.61676e-06" />
            <origin xyz="1.41504e-09 -0.0206684 0.0154625" rpy="0 -0 0" />
            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
        </inertial>
        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
    </link>
    <link name="part_1_1">
        <inertial>
            <mass value="1.83642e-06" />
            <origin xyz="-0.0387433 0.00087367 2.19005e-08" rpy="0 -0 0" />
            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
        </inertial>
        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
    </link>
    <link name="part_2">
        <inertial>
            <mass value="2.57408e-07" />
            <origin xyz="2.02927e-08 0.00444918 -0.0105" rpy="0 -0 0" />
            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
        </inertial>
        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
    </link>
    <link name="part_3">
        <inertial>
            <mass value="3.79331e-05" />
            <origin xyz="0.00137248 0.0100826 -8.79377e-06" rpy="0 -0 0" />
            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
        </inertial>
        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
    </link>
    <link name="part_4">
        <inertial>
            <mass value="8.05142e-06" />
            <origin xyz="0.00247423 0.00507451 -8.57508e-05" rpy="0 -0 0" />
            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
        </inertial>
        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
    </link>
    <link name="part_5">
        <inertial>
            <mass value="1.23238e-07" />
            <origin xyz="8.93851e-05 3.62593e-05 0.0114722" rpy="0 -0 0" />
            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
        </inertial>
        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
    </link>
    <link name="root" />
    <link name="xm430_w350">
        <inertial>
            <mass value="3.876e-08" />
            <origin xyz="7.25597e-20 0.0103899 -0.015278" rpy="0 -0 0" />
            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
        </inertial>
        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
    </link>
    <link name="xm430_w350_1">
        <inertial>
            <mass value="2.20536e-05" />
            <origin xyz="2.83359e-19 -0.0119648 -3.55124e-06" rpy="0 -0 0" />
            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
        </inertial>
        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
    </link>
    <link name="xm430_w350_2">
        <inertial>
            <mass value="1.07968e-05" />
            <origin xyz="-0.011 0.0199318 -0.00430418" rpy="0 -0 0" />
            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
        </inertial>
        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
    </link>
    <link name="xm430_w350_3">
        <inertial>
            <mass value="8.00924e-06" />
            <origin xyz="7.25466e-18 -0.0136602 -0.0124626" rpy="0 -0 0" />
            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
        </inertial>
        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
    </link>
    <joint name="fastened_1" type="fixed">
        <origin xyz="-0.0279995 0.01975 0.000171175" rpy="-1.56468 3.88578e-16 1.5708" />
        <axis xyz="0 0 -1" />
        <parent link="fr12_h101k" />
        <child link="part_1" />
    </joint>
    <joint name="fastened_1_1" type="fixed">
        <origin xyz="3.55971e-16 0.00615 -0.0085" rpy="4.65079e-15 -2.67245e-14 -3.14159" />
        <axis xyz="-0 -0 1" />
        <parent link="part_3" />
        <child link="assembly_2__1_" />
    </joint>
    <joint name="fastened_1_2" type="fixed">
        <origin xyz="-0.011 0.032 0.00345" rpy="-9.02564e-64 -9.7633e-32 1.84889e-32" />
        <axis xyz="0 0 -1" />
        <parent link="xm430_w350_2" />
        <child link="hn12_n101" />
    </joint>
    <joint name="fastened_2" type="fixed">
        <origin xyz="-5.23128e-18 -0.0235 0.027" rpy="-1.42941e-15 -4.43148e-16 -3.14159" />
        <axis xyz="-0 1 -0" />
        <parent link="part_1" />
        <child link="part_4" />
    </joint>
    <joint name="fastened_2_1" type="fixed">
        <origin xyz="3.33067e-16 -1.62933e-05 0.00075" rpy="-9.02564e-64 -9.7633e-32 1.84889e-32" />
        <axis xyz="-0 -0 -1" />
        <parent link="hn12_n101" />
        <child link="dynamixel_xm430_w350_t__1_" />
    </joint>
    <joint name="fastened_3" type="fixed">
        <origin xyz="-1.75554e-15 3.67761e-16 -0.017" rpy="-9.02564e-64 -9.7633e-32 1.84889e-32" />
        <axis xyz="0 0 1" />
        <parent link="xm430_w350_3" />
        <child link="hn12_n101_1" />
    </joint>
    <joint name="fastened_4" type="fixed">
        <origin xyz="0.017 -0.011 -0.0085" rpy="-1.5708 -2.22045e-16 -1.5708" />
        <axis xyz="0 0 1" />
        <parent link="fr12_s102k" />
        <child link="xm430_w350_2" />
    </joint>
    <joint name="fixed_node_to_root_joint" type="fixed">
        <origin xyz="-0.000146928 0.03665 -0.106001" rpy="2.77556e-17 6.9315e-17 8.04996e-19" />
        <axis xyz="0 0 1" />
        <parent link="root" />
        <child link="dynamixel_xm430_w350_r__solid_1__dynamixel_xm430_w350_r__solid_1" />
    </joint>
    <joint name="group_1_fastened_joint" type="fixed">
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

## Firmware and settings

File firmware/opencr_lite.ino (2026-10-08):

// OpenCR / XM430-W350: pan ID11, tilt ID12.
// USB at 115200: v PAN TILT (rad/s), p (read), x (stop).
// Reply: P1 SAMPLE PAN_TICKS TILT_TICKS FAULT\n.
// On fault, an F1 diagnostic precedes P1; the first failure is retained.
#include <Dynamixel2Arduino.h>
#include <math.h>
#include <stdio.h>
#include <stdlib.h>
#include <string.h>

constexpr uint8_t AXES = 2;
constexpr uint32_t CYCLE_US = 10000;  // 100 Hz target
constexpr uint32_t COMMAND_TIMEOUT_MS = 200;
// Response deadline, not a fixed delay: successful reads return immediately.
// Allow both motors to reply; the previous 2 ms budget caused missing replies.
constexpr uint32_t MOTOR_TIMEOUT_MS = 500;
constexpr float SPEED_UNIT = 1.374f * PI / 180.0f;
constexpr float MAX_RAD_S = 1.0f;
constexpr int32_t MAX_POSITION = 1048575;
constexpr int32_t TRAVEL_TOLERANCE = 8;

namespace Reg {
constexpr uint16_t DRIVE = 10, MODE = 11, HOME_OFFSET = 20;
constexpr uint16_t SPEED_LIMIT = 44, TORQUE = 64, ERROR = 70;
constexpr uint16_t WATCHDOG = 98, ACCELERATION = 108;
constexpr uint16_t PROFILE = 112, GOAL = 116, POSITION = 132;
}

struct Axis {
  uint8_t id;
  int32_t home, lower, upper;
  int32_t position, origin, speed_limit, applied;
  int32_t profile, goal;
  bool ready;
};

// Home-relative limits, rounded inward to whole encoder ticks.
Axis axes[AXES] = {
  {11, 0, -2048, 2048},    // pan: -180 to +180 degrees
  {12, 2048, -1365, 1365}  // tilt: -120 to +120 degrees
};
int32_t requested[AXES] = {};
bool faulted = false, command_active = false;
uint32_t command_ms = 0, cycle_us = 0, sample = 0;

Dynamixel2Arduino motors(Serial3, 84);
ParamForSyncReadInst_t read_packet;
ParamForSyncWriteInst_t write_packet;
RecvInfoFromStatusInst_t replies;

// Retain the first failure before stopMotion() performs further motor I/O.
const char *fault_reason = nullptr;
uint8_t fault_id = 0;
uint16_t fault_register = 0;
int32_t fault_value = 0;
int fault_lib = 0, fault_status = 0;

bool failure(const char *reason, uint8_t id, uint16_t addr, int32_t value) {
  if (!fault_reason) {
    fault_reason = reason;
    fault_id = id;
    fault_register = addr;
    fault_value = value;
    fault_lib = motors.getLastLibErrCode();
    fault_status = motors.getLastStatusPacketError();
  }
  return false;
}

// Motor I/O. Every response must be complete and error-free.
bool responseOK() {
  return motors.getLastLibErrCode() == DXL_LIB_OK &&
    motors.getLastStatusPacketError() == 0;
}

bool readMotor(uint8_t i, uint16_t addr, void *data, uint16_t size) {
  int count = motors.read(axes[i].id, addr, size, (uint8_t *)data, size,
    MOTOR_TIMEOUT_MS);
  return (count == size && responseOK()) ||
    failure("read", axes[i].id, addr, count);
}

bool writeMotor(uint8_t i, uint16_t addr, int32_t value, uint16_t size) {
  return (motors.write(axes[i].id, addr,
    (uint8_t *)&value, size, MOTOR_TIMEOUT_MS) && responseOK()) ||
    failure("write", axes[i].id, addr, value);
}

bool configure(uint8_t i, uint16_t addr, int32_t value, uint16_t size) {
  int32_t actual = 0;
  if (!readMotor(i, addr, &actual, size)) return false;
  if (actual == value) return true;
  return writeMotor(i, addr, value, size) &&
    readMotor(i, addr, &actual, size) &&
    (actual == value || failure("verify", axes[i].id, addr, actual));
}

bool readBoth(uint16_t addr, uint16_t size) {
  read_packet.addr = addr;
  read_packet.length = size;
  if (!motors.syncRead(read_packet, replies, MOTOR_TIMEOUT_MS) ||
      replies.id_count != AXES) {
    uint8_t missing = replies.id_count < AXES ? axes[replies.id_count].id : 0;
    return failure("sync_read", missing, addr, replies.id_count);
  }
  for (uint8_t i = 0; i < AXES; ++i) {
    const auto &reply = replies.xel[i];
    if (reply.id != axes[i].id || reply.error || reply.length != size)
      return failure("sync_reply", axes[i].id, addr, reply.error);
  }
  return true;
}

// Read measured position and check the motor failsafes each cycle.
bool readPosition() {
  if (!readBoth(Reg::POSITION, 4)) return false;
  for (uint8_t i = 0; i < AXES; ++i) {
    memcpy(&axes[i].position, replies.xel[i].data, 4);
    int64_t relative = (int64_t)axes[i].position - axes[i].origin;
    if (relative < axes[i].lower - TRAVEL_TOLERANCE ||
        relative > axes[i].upper + TRAVEL_TOLERANCE)
      return failure("travel_range", axes[i].id, Reg::POSITION, relative);
  }
  if (!readBoth(Reg::TORQUE, 7)) return false;
  for (uint8_t i = 0; i < AXES; ++i) {
    const uint8_t *data = replies.xel[i].data;
    if (data[0] != 1)
      return failure("torque_off", axes[i].id, Reg::TORQUE, data[0]);
    if (data[Reg::ERROR - Reg::TORQUE])
      return failure("hardware_error", axes[i].id, Reg::ERROR,
        data[Reg::ERROR - Reg::TORQUE]);
  }
  if (!readBoth(Reg::WATCHDOG, 1)) return false;
  for (uint8_t i = 0; i < AXES; ++i)
    if (replies.xel[i].data[0] == 255)
      return failure("watchdog", axes[i].id, Reg::WATCHDOG, 255);
  return true;
}

void stopMotion() {
  command_active = false;
  for (uint8_t i = 0; i < AXES; ++i) {
    Axis &axis = axes[i];
    int32_t position;
    requested[i] = axis.applied = 0;
    if (axis.ready && readMotor(i, Reg::POSITION, &position, 4) &&
        writeMotor(i, Reg::GOAL, position, 4)) {
      axis.goal = position;
    } else {
      failure("stop", axis.id, Reg::GOAL, axis.ready);
      faulted = true;
      writeMotor(i, Reg::TORQUE, 0, 1);
    }
  }
}

void latchFault() {
  faulted = true;  // restart the board to clear a fault
  stopMotion();
}

// Speed magnitude sets the profile; direction selects the travel boundary.
// Extended Position mode decelerates and holds at that bounded target.
bool writeSpeed() {
  bool changed = false;
  for (uint8_t i = 0; i < AXES; ++i)
    changed |= requested[i] != axes[i].applied;
  if (!changed) return true;
  for (uint8_t i = 0; i < AXES; ++i) {
    Axis &axis = axes[i];
    int32_t speed = requested[i];
    if (speed != axis.applied) {
      axis.profile = speed == 0 ? 1 : abs(speed);
      axis.goal = speed == 0 ? axis.position :
        axis.origin + (speed > 0 ? axis.upper : axis.lower);
    }
    // Profile zero means unlimited speed, so zero commands hold position.
    int32_t data[] = {axis.profile, axis.goal};
    memcpy(write_packet.xel[i].data, data, sizeof(data));
  }
  if (!motors.syncWrite(write_packet))
    return failure("sync_write", 0, Reg::PROFILE, 0);
  if (!readBoth(Reg::PROFILE, 8)) return false;
  for (uint8_t i = 0; i < AXES; ++i) {
    if (memcmp(replies.xel[i].data, write_packet.xel[i].data, 8))
      return failure("profile_verify", axes[i].id, Reg::PROFILE, 0);
    axes[i].applied = requested[i];
  }
  return true;
}

bool prepareMotor(uint8_t i) {
  Axis &axis = axes[i];
  int32_t offset = 0, error = 0, drive = 0;
  if (!motors.ping(axis.id)) return failure("ping", axis.id, 0, 0);
  uint16_t model = motors.getModelNumber(axis.id);
  if (model != XM430_W350) return failure("model", axis.id, 0, model);
  if (!configure(i, Reg::TORQUE, 0, 1) ||
      !configure(i, Reg::WATCHDOG, 0, 1) ||
      !readMotor(i, Reg::HOME_OFFSET, &offset, 4)) return false;
  if (offset != 0) return failure("home_offset", axis.id, Reg::HOME_OFFSET, offset);
  if (!readMotor(i, Reg::ERROR, &error, 1)) return false;
  if (error != 0) return failure("hardware_error", axis.id, Reg::ERROR, error);
  if (!readMotor(i, Reg::DRIVE, &drive, 1)) return false;
  // Preserve direction; clear time-profile and torque-on-by-goal bits.
  if (!configure(i, Reg::DRIVE, drive & ~12, 1) ||
      !configure(i, Reg::MODE, 4, 1) ||
      !readMotor(i, Reg::SPEED_LIMIT, &axis.speed_limit, 4)) return false;
  if (axis.speed_limit < 1 || axis.speed_limit > 1023)
    return failure("speed_limit", axis.id, Reg::SPEED_LIMIT, axis.speed_limit);
  if (!readMotor(i, Reg::POSITION, &axis.position, 4)) return false;
  int32_t relative = ((int64_t)axis.position - axis.home) % 4096;
  if (relative > 2048) relative -= 4096;
  if (relative < -2048) relative += 4096;
  if (relative < axis.lower || relative > axis.upper)
    return failure("startup_range", axis.id, Reg::POSITION, relative);
  int64_t origin = (int64_t)axis.position - relative;
  if (origin + axis.lower < -MAX_POSITION ||
      origin + axis.upper > MAX_POSITION)
    return failure("origin_range", axis.id, Reg::POSITION, axis.position);
  axis.origin = origin;
  axis.profile = 1;
  axis.goal = axis.position;
  axis.ready = configure(i, Reg::ACCELERATION, 8, 4) &&
    configure(i, Reg::PROFILE, axis.profile, 4) &&
    configure(i, Reg::GOAL, axis.goal, 4) &&
    configure(i, Reg::TORQUE, 1, 1) &&
    configure(i, Reg::WATCHDOG, COMMAND_TIMEOUT_MS / 20, 1);
  return axis.ready;
}

// Serial interface: p reads position; v writes angular speed; x stops.
void sendPosition() {
  char line[160];
  if (faulted && fault_reason && Serial) {
    int length = snprintf(line, sizeof(line), "F1 %s %u %u %ld %d %d\n",
      fault_reason, (unsigned)fault_id, (unsigned)fault_register,
      (long)fault_value, fault_lib, fault_status);
    if (length > 0 && length < (int)sizeof(line))
      Serial.write((uint8_t *)line, length);
  }
  int length = snprintf(line, sizeof(line), "P1 %lu %ld %ld %u\n",
    (unsigned long)sample,
    (long)((int64_t)axes[0].position - axes[0].origin),
    (long)((int64_t)axes[1].position - axes[1].origin),
    (unsigned)faulted);
  if (Serial && length > 0 && length < (int)sizeof(line))
    Serial.write((uint8_t *)line, length);
}

void command(char *line) {
  if (!strcmp(line, "p")) { sendPosition(); return; }
  if (!strcmp(line, "x")) { stopMotion(); return; }
  if (faulted) return;
  if (line[0] != 'v' || line[1] != ' ') { stopMotion(); return; }
  char *cursor = line + 2, *end;
  int32_t speeds[AXES];
  for (uint8_t i = 0; i < AXES; ++i) {
    float speed = strtof(cursor, &end);
    if (cursor == end || !isfinite(speed) || fabsf(speed) > MAX_RAD_S ||
        fabsf(speed) > axes[i].speed_limit * SPEED_UNIT) {
      stopMotion();
      return;
    }
    speeds[i] = speed / SPEED_UNIT;
    cursor = end;
    if (i == 0 && *cursor != ' ') { stopMotion(); return; }
  }
  while (*cursor == ' ' || *cursor == '\t') ++cursor;
  if (*cursor) { stopMotion(); return; }
  memcpy(requested, speeds, sizeof(speeds));
  command_ms = millis();
  command_active = true;
}

void readCommands() {
  static char line[64];
  static uint8_t used = 0;
  static bool discard = false;
  for (uint8_t n = 0; n < 64 && Serial.available(); ++n) {
    char c = Serial.read();
    if (c == '\n') {
      line[used] = 0;
      if (!discard) command(line);
      used = 0;
      discard = false;
    } else if (c != '\r' && !discard) {
      if (c < 32 || c > 126 || used == sizeof(line) - 1) {
        discard = true;
        stopMotion();
      } else {
        line[used++] = c;
      }
    }
  }
}

void setup() {
  Serial.begin(115200);
  motors.begin(1000000);
  motors.setPortProtocolVersion(2.0);
  read_packet.id_count = write_packet.id_count = AXES;
  write_packet.addr = Reg::PROFILE;
  write_packet.length = 8;
  for (uint8_t i = 0; i < AXES; ++i)
    read_packet.xel[i].id = write_packet.xel[i].id = axes[i].id;
  delay(1000);
  if (!prepareMotor(0) || !prepareMotor(1)) latchFault();
}

void loop() {
  if (command_active &&
      (!Serial || millis() - command_ms >= COMMAND_TIMEOUT_MS))
    stopMotion();
  readCommands();
  if (faulted || (uint32_t)(micros() - cycle_us) < CYCLE_US) return;
  cycle_us = micros();
  if (!readPosition() || !writeSpeed()) { latchFault(); return; }
  ++sample;
}

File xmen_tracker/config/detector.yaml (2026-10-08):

# xmen_tracker 검출 설정(tracker_node의 detector_config 기본값, tuning·evaluate 공용) — 코드 수정 없이 이 파일만 바꿔서 튜닝한다.
# camera: 절의 노출·화이트밸런스는 realsense_node 파라미터로 같은 값을 적용한다(white_balance 4600 등).
# 목표: 파란 30×30×60 mm 직육면체, 어두움~밝음, 0.1~1 m. 세 장면(보임·없음·가림)은 같은 설정으로 확인한다.

target:
  name: blue_cube            # 사진·결과 JSON에 기록되는 목표 이름
  # OpenCV HSV 범위: H 0~179, S 0~255, V 0~255
  # 빨강처럼 H가 0/179 경계를 넘는 색은 범위를 두 개 적는다(합집합).
  # 실측(<ws>/results/perception/dataset, 조명 3 × 거리 0.15~1.0 m, 1,400장) 기준 최적화:
  #   큐브 H 110~113, S 248~255, V 38~46(어두움)·84~103(보통·밝음)
  #   배경(보라 의자·청회색 카펫)의 H 100~125 픽셀: S 중앙값 69~83, 상위 1% 124~163
  #   S 하한 170~230에서만 인식 100%·오검출 0% → 가운데 200. H는 큐브 112 중심 ±8.
  hsv_ranges:
    - lower: [104, 200, 8]
      upper: [120, 255, 255]
  # 완화 범위(relaxed_ranges)는 쓰지 않는다: 배경 S가 80~125라 큐브에 붙은 의자·카펫까지 큐브로 번져
  # 크기 불일치로 탈락했다(어두움 0%, 밝음 57%). 제거 후 실측 인식 100%.
  # 색 세기(max−min) 하한: 어두운 픽셀의 S는 잡음만으로 커지므로 잡음 수준 이하는 버린다.
  min_chroma: 5
  # 크기 기반 면적 제한(selection의 auto): size_mm 크기의 물체가 distance_range_m 범위에 있다고 본다.
  # 최소 면적 = 1 m에서 끝면(30×30)이 보일 때, 최대 면적 = 0.1 m에서 옆면(30×60)이 보일 때 기준.
  size_mm: [30, 30, 60]      # 가로·세로·높이 [mm]. 정육면체면 숫자 하나
  distance_range_m: [0.1, 1.0]

camera:
  backend: realsense         # realsense(pyrealsense2) | v4l2(OpenCV VideoCapture, 예비용)
  device: 6                  # v4l2 장치 번호(backend: v4l2일 때만). 이 PC에서는 /dev/video6 = D435 컬러
  fps: 30
  warmup_frames: 30          # 자동 노출·화이트밸런스 안정화용으로 버리는 프레임 수
  # HSV 값은 노출·화이트밸런스가 바뀌면 같이 변한다. 튜닝 후에는 고정을 권장한다.
  # null = 자동. tune 모드에서 현재 자동값이 출력되니 그 값을 적으면 된다.
  # 조명이 바뀌는 환경: 노출은 자동(밝기 변화를 카메라가 흡수), 화이트밸런스는 고정(색상 H가 흔들리지 않게).
  # 노출을 고정하면 어두운 곳에서 V가 그대로 떨어진다. 4600 K = 이 방에서 측정한 자동 화이트밸런스 값.
  exposure: null             # RealSense 컬러 노출(1~10000, 단위 0.1ms 상당). null = 자동
  white_balance: 4600        # RealSense 화이트밸런스(2800~6500 K). null = 자동
  options:                   # 그 밖의 RealSense 컬러 옵션(이름: 값) — 실제 카메라에서 확인 필요
    auto_exposure_priority: 1  # 1 = 어두우면 프레임률을 낮춰서라도 노출을 늘림(잡음↓, 30→15 fps 가능)
    backlight_compensation: 0  # 역광 보정 끔(밝은 배경 앞 큐브가 더 어두워지는 것 방지 효과는 실측으로 확인)
  fx_px: 460.0               # 컬러 초점거리 [px] @ fx_width. 640×360(16:9)은 약 460, 640×480(4:3)은 약 615.
  fx_width: 640              # RealSense 실행 시 실제 내부 파라미터로 덮어쓰고 면적 기준을 다시 계산한다

processing:
  # 처리 해상도. 입력이 다르면 이 크기로 리사이즈한 뒤 처리한다.
  # 면적 기준(min_area)은 이 해상도 기준 픽셀 수다.
  # D435는 630×360 같은 임의 크기를 지원하지 않는다. 640×360은 컬러·뎁스 모두 지원.
  # 비율이 다른 입력(640×480 사진·모의 영상)은 늘리지 않고 가운데를 16:9로 잘라서 쓴다(위아래 60줄씩).
  width: 640
  height: 360
  blur_ksize: 5              # 가우시안 블러 커널(홀수, 0이면 생략)
  morph_kernel: 5            # 모폴로지 커널 크기
  open_iterations: 1         # 열림: 작은 점 잡음 제거
  close_iterations: 2        # 닫힘: 물체 내부 구멍·틈 메우기

selection:
  # 뎁스가 없을 때(사진·웹캠·뎁스 끔)의 최소 면적. 뎁스가 있으면 depth.min_area_px와 실제 크기 검사를 쓴다.
  min_area: auto             # auto = min_area_factor × (가장 먼 거리에서 가장 작은 면 30×30의 넓이)
  min_area_factor: 0.3       # 회전·가림·원근 여유. 640×360·fx 460·1 m → 0.3 × 190 ≈ 57 px
  max_area_ratio: auto       # auto = 가장 가까운 거리에서 가장 큰 면 30×60 기준(최소 0.6, 최대 0.95)
  max_aspect: 3.0            # 외접 사각형 긴 변/짧은 변. 30×60 옆면은 2:1 — 이보다 훨씬 긴 줄무늬·막대 제거
  # 큐브가 아닌 같은 색 물체(홈·구멍이 있는 파란 3D 프린트 브래킷, 크기 5×6.5 cm로 크기 검사 통과) 구분:
  #   실측 큐브 1,100개 solidity 0.91~1.00·extent 0.84~0.99, 브래킷 3장 solidity 0.67~0.68·extent 0.52~0.53
  #   0.80/0.68은 손가락이 큐브를 가로질러 가릴 때 1 m에서 큐브가 떨어져(모의 107→97/110) 0.75/0.60으로 둔다
  min_extent: 0.60           # 면적/minAreaRect 면적. 홈이 있거나 구불구불한 덩어리 제거
  min_solidity: 0.75         # 면적/볼록껍질 면적. 오목한 부분이 많은 물체 제거(큐브는 반쯤 가려도 0.98)
  # 사각 면으로 된 상자인지(box_fit): 실루엣(볼록껍질)을 꼭짓점 ≤ max_vertices 다각형으로 근사했을 때의
  # 평균 틈 = (껍질 넓이 − 다각형 넓이)/둘레/√넓이 가 base + pixel/√넓이 이하여야 한다.
  #   실측 큐브 ≤ 0.016, 비스듬한 상자(렌더) ≤ 0.033(1,600 px)·0.047(430 px), 원·타원 ≥ 0.044(600 px 이상)
  #   → 원·타원·고리를 거른다. 반원은 직선 변이 있어 통과한다.
  #   min_px 미만(약 0.7 m보다 멂)은 해상도가 부족해 원과 상자를 구분할 수 없어 검사하지 않는다.
  box_fit:
    enabled: true
    max_vertices: 6          # 상자 실루엣은 4(정면)~6(비스듬)각형
    base: 0.02
    pixel: 0.7               # 허용 틈: 500 px → 0.051, 1,500 px → 0.038, 5,000 px → 0.030
    min_px: 500              # 이보다 작은 실루엣은 검사하지 않음
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

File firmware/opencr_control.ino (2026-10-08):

// OpenCR 통합 제어 펌웨어 (OPENCR_CONTROL_V3_RAD_VELOCITY)
//
// 흐름: Raspberry Pi main.py -> USB Serial(115200) -> OpenCR -> DYNAMIXEL(1 Mbps)
// 모터: X축(좌우, pan)  ID11, 홈 0틱
//       Y축(상하, tilt) ID12, 홈 2048틱
//
// 명령:
//   v PAN TILT    ID11/ID12 속도 (rad/s), 0은 위치 유지, 500ms 갱신 없으면 정지
//   DX DY SPEED   현재 목표 기준 상대 이동 (deg, deg, deg/s)
//   h             홈 복귀 (Y축 -> X축 순서)
//   x             즉시 정지하고 위치 저장
//   off           토크 해제 (카메라를 먼저 받칠 것)
//   p             상태 출력
//   scan          모터 진단
//   auto on/off   부팅 시 홈 복귀 / 저장 위치 복원
//
// 이동 결과는 홈 기준 X +/-180°, Y +/-135° 안에 있어야 한다.
// 마지막 정지 위치는 EEPROM에 저장하고 부팅할 때 복원한다.

#include <Dynamixel2Arduino.h>
#include <EEPROM.h>
#include <math.h>
#include <stdlib.h>
#include <string.h>
#include <ctype.h>

using namespace ControlTableItem;

// ============================================================
// 하드웨어 설정
// ============================================================

Dynamixel2Arduino dxl(Serial3, 84);  // DYNAMIXEL 포트, 방향 제어 핀 84
const char CONTROL_BUILD_ID[] = "OPENCR_CONTROL_V3_RAD_VELOCITY";

// 내부 배열 순서는 Y축이 0번, X축이 1번이다. (입력 순서 X, Y와 반대)
const uint8_t AXIS_Y = 0;
const uint8_t AXIS_X = 1;
const uint8_t AXIS_COUNT = 2;

const uint8_t ids[AXIS_COUNT] = {12, 11};
const int32_t homes[AXIS_COUNT] = {2048, 0};          // Y=180°, X=0° 위치의 엔코더 값
const float angle_limits[AXIS_COUNT] = {135, 180};   // 홈 기준 허용 각도 (+/-deg)

// ============================================================
// 단위와 동작 기준값
// ============================================================

const int32_t TICKS_PER_REV = 4096;                // 모터 한 바퀴 = 4096틱
const float VELOCITY_UNIT_DEG_S = 1.374f;          // Profile Velocity 1 = 1.374 deg/s
const float VELOCITY_UNIT_RAD_S = VELOCITY_UNIT_DEG_S * PI / 180.0f;
const uint32_t VELOCITY_COMMAND_TIMEOUT_MS = 500;
const float ACCEL_UNIT_DEG_S2 = 21.4577f;          // Profile Acceleration 1 = 21.4577 deg/s^2
const float ACCEL_TIME_S = 0.3f;                   // 설정 속도까지 걸리는 시간
const int32_t VELOCITY_LIMIT_MAX = 1023;
const int32_t EXTENDED_POSITION_MAX = 1048575;     // Extended Position 모드의 목표 범위
const uint8_t WATCHDOG_500MS = 25;                 // Bus Watchdog 1 = 20ms
const uint16_t ADDR_BUS_WATCHDOG = 98;             // XM430: exactly ONE byte
const uint16_t ADDR_PROFILE_ACCELERATION = 108;    // Sync Write 시작 주소

const float RETURN_SPEED_DEG_S = 30;               // 홈 복귀와 위치 복원 속도
const uint32_t POLL_INTERVAL_MS = 100;             // 모터 상태 점검 주기
const uint32_t MOVE_TIMEOUT_BASE_MS = 15000;       // 이동 제한 시간의 기본값
const int32_t ARRIVAL_TOLERANCE_TICKS = 8;         // 약 0.7° 이내면 도착
const uint8_t SETTLE_COUNT = 5;                    // 연속 도착 판정 횟수 (약 0.5초)

// ============================================================
// 제어 상태
// ============================================================

int32_t targets[AXIS_COUNT];   // 현재 목표 위치 (엔코더 틱)
int32_t anchors[AXIS_COUNT];   // 홈에 해당하는 실제 엔코더 틱. 홈 기준 위치 = targets - anchors
bool configured[AXIS_COUNT] = {false, false};

bool active = false;     // 이동 중
bool sequence = false;   // 순차 이동(홈 복귀·위치 복원) 중
bool faulted = false;    // 오류로 정지. 재시작 전까지 유지된다.
const char *reason = "none";

// 두 축 동시 이동
bool dual_move = false;
bool velocity_stream = false;
int32_t stream_velocity[AXIS_COUNT] = {0, 0};  // signed motor units; Y, X
uint32_t velocity_command_ms = 0;
uint8_t dual_settled[AXIS_COUNT] = {0, 0};
float dual_speeds[AXIS_COUNT] = {5, 5};

// 순차 이동: Y축을 먼저 옮기고, 도착하면 X축을 옮긴다.
float stage_speed = RETURN_SPEED_DEG_S;
const char *sequence_name = "HOME";
int32_t sequence_ticks[AXIS_COUNT] = {0, 0};   // 홈 기준 목표 틱
uint8_t stage = 0;                             // 지금 움직이는 축
uint8_t settled = 0;
uint32_t stage_ms = 0;                         // 이동 시작 시각
uint32_t poll_ms = 0;                          // 마지막 점검 시각

// ============================================================
// EEPROM 저장 구조
// ============================================================

// 주소 0: 부팅 시 자동 홈 복귀 설정
bool auto_home = false;

struct BootSetting {
  uint32_t magic;
  uint8_t enabled;
  uint8_t inverse;
};

const uint32_t BOOT_MAGIC = 0x43414D32;

// 주소 16: 마지막 정지 위치 (홈 기준 틱)
struct SavedPosition {
  uint32_t magic;
  int32_t ticks[AXIS_COUNT];
  uint32_t check;
};

const int POSITION_ADDR = 16;
const uint32_t POSITION_MAGIC = 0x504F5331;
const int32_t RESTORE_TOLERANCE = 12;   // 약 1.05° 이내면 같은 위치로 본다.
bool saved_valid = false;
int32_t saved_ticks[AXIS_COUNT] = {0, 0};

// ============================================================
// 기본 보조 함수
// ============================================================

// 모터의 제어 테이블 항목 하나를 읽는다. 통신·상태 오류가 없을 때만 true.
bool readValue(uint8_t id, uint8_t item, int32_t &value) {
  // Dynamixel2Arduino 0.8.2 incorrectly declares this XM430 item as 2 bytes.
  // Read only address 98; 0xFF represents the signed watchdog error value -1.
  if (item == BUS_WATCHDOG) {
    uint8_t raw = 0;
    if (dxl.read(id, ADDR_BUS_WATCHDOG, 1, &raw, sizeof(raw), 30) != 1 ||
        dxl.getLastLibErrCode() != DXL_LIB_OK || dxl.getLastStatusPacketError() != 0) return false;
    value = raw == 0xFF ? -1 : raw;
    return true;
  }
  const int32_t result = dxl.readControlTableItem(item, id, 30);
  if (dxl.getLastLibErrCode() != DXL_LIB_OK || dxl.getLastStatusPacketError() != 0) return false;
  value = result;
  return true;
}

// 통신 성공뿐 아니라 실제 레지스터 값까지 확인한다. 위치는 signed 32-bit 틱으로 쓴다.
bool verifyValue(uint8_t id, uint8_t item, int32_t expected) {
  int32_t actual;
  return readValue(id, item, actual) && actual == expected;
}

bool writeValue(uint8_t id, uint8_t item, int32_t value) {
  if (item == BUS_WATCHDOG) {
    if (value < 0 || value > 127) return false;
    const uint8_t raw = static_cast<uint8_t>(value);
    const bool written = dxl.write(id, ADDR_BUS_WATCHDOG, &raw, sizeof(raw), 30);
    if (!written || dxl.getLastLibErrCode() != DXL_LIB_OK || dxl.getLastStatusPacketError() != 0) {
      Serial.print("WATCHDOG_WRITE_ERROR id=");
      Serial.print(id);
      Serial.print(" lib=");
      Serial.print(dxl.getLastLibErrCode());
      Serial.print(" status=");
      Serial.println(dxl.getLastStatusPacketError());
      return false;
    }
    int32_t actual;
    if (!readValue(id, BUS_WATCHDOG, actual)) {
      Serial.print("WATCHDOG_READ_ERROR id=");
      Serial.println(id);
      return false;
    }
    if (actual != value) {
      Serial.print("WATCHDOG_VERIFY_ERROR id=");
      Serial.print(id);
      Serial.print(" expected=");
      Serial.print(value);
      Serial.print(" actual=");
      Serial.println(actual);
      return false;
    }
    return true;
  }
  if (!dxl.writeControlTableItem(item, id, value, 30) ||
      dxl.getLastLibErrCode() != DXL_LIB_OK || dxl.getLastStatusPacketError() != 0) return false;
  return verifyValue(id, item, value);
}

bool writePosition(uint8_t id, int32_t ticks) {
  return ticks >= -EXTENDED_POSITION_MAX && ticks <= EXTENDED_POSITION_MAX &&
         writeValue(id, GOAL_POSITION, ticks);
}
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

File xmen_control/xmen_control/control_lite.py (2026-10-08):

"""Home once at startup, then bridge Twist and JointState over USB."""
import math
import time
from contextlib import suppress
import serial
import rclpy
from rclpy.node import Node
from geometry_msgs.msg import Twist
from sensor_msgs.msg import JointState

PERIOD, TIMEOUT = 0.01, 0.2
WRITE_TIMEOUT = 0.1  # allow USB scheduling jitter; firmware watchdog stays 0.2s
MAX_SPEED, HOME_SPEED, HOME_TIMEOUT = 1.0, 0.3, 30.0
TICK_RAD = 2 * math.pi / 4096
HOME_TOLERANCE, SETTLE_TIME = 8 * TICK_RAD, 0.2
HOME_APPROACH_TOLERANCE = 4 * TICK_RAD
HOME_ATTEMPTS = 3
POSITION_LIMITS = ((-2048, 2048), (-1365, 1365))  # pan +/-180, tilt +/-120 deg
POSITION_TOLERANCE = 8  # match the firmware feedback tolerance


class OpenCRBridge(Node):
    def __init__(self):
        super().__init__('control_lite')
        port = self.declare_parameter('port', '/dev/ttyACM0').value
        self.board = serial.Serial(
            port, 115200, timeout=0, write_timeout=WRITE_TIMEOUT, exclusive=True)
        self.board.reset_input_buffer()
        self.start_at = self.sample_at = time.monotonic() + 1.5
        self.sample = self.position = self.pending = None
        self.command_at, self.buffer = 0.0, b''
        self.startup = self.home()  # runs once, on fresh feedback
        self.positions = self.create_publisher(JointState, '/joint_states', 1)
        self.commands = self.create_subscription(
            Twist, '/cmd_vel', self.write_speed, 1)
        self.timer = self.create_timer(PERIOD, self.tick)

    def send(self, text):
        data = (text + '\n').encode('ascii')
        try:
            written = self.board.write(data)
        except serial.SerialTimeoutException as error:
            raise OSError(
                f'USB write timed out after {WRITE_TIMEOUT:.2f}s '
                f'(command={text!r})') from error
        if written != len(data):
            raise OSError('Incomplete serial write')

    def write_speed(self, msg):
        if self.sample is None or self.startup is not None: return
        speed = (msg.angular.z, msg.angular.y)  # pan, tilt; rad/s
        valid = all(math.isfinite(v) and abs(v) <= MAX_SPEED for v in speed)
        self.pending = speed if valid else (0.0, 0.0)
        self.command_at = time.monotonic()

    def read_position(self, line, now):
        fields = line.split()
        if len(fields) == 7 and fields[0] == b'F1':
            reason = fields[1].decode('ascii')
            motor, register, value, library, status = map(int, fields[2:])
            raise ValueError(
                f'OpenCR fault: {reason}; motor_id={motor}, '
                f'register={register}, value={value}, '
                f'library_error={library}, status_error={status}')
        if len(fields) != 5 or fields[0] != b'P1':
            raise ValueError(
                f'Unexpected firmware reply: {line[:160]!r}; '
                'expected P1 SAMPLE PAN_TICKS TILT_TICKS FAULT from '
                'opencr_lite.ino. Full control firmware is incompatible')
        sample, pan, tilt, fault = map(int, fields[1:])
        details = f'sample={sample}, pan={pan}, tilt={tilt}, fault={fault}'
        if fault:
            raise ValueError(
                f'OpenCR firmware fault latched ({details}); '
                'check motor power/communication, startup position and motor '
                'status, then restart the OpenCR board before restarting '
                'the bridge')
        if not 0 <= sample <= 0xffffffff:
            raise ValueError(f'Invalid OpenCR sample counter ({details})')
        for name, position, (low, high) in zip(
                ('pan', 'tilt'), (pan, tilt), POSITION_LIMITS):
            if not low - POSITION_TOLERANCE <= position <= high + POSITION_TOLERANCE:
                raise ValueError(
                    f'OpenCR {name} position out of range ({details}); '
                    f'expected {low}..{high} ticks with '
                    f'{POSITION_TOLERANCE}-tick tolerance')
        if sample == self.sample: return
        self.sample, self.sample_at = sample, now
        self.position = [pan * TICK_RAD, tilt * TICK_RAD]
        msg = JointState()
        msg.header.stamp = self.get_clock().now().to_msg()
        msg.name, msg.position = ['pan', 'tilt'], self.position
        self.positions.publish(msg)

    def home(self):
        for attempt in range(1, HOME_ATTEMPTS + 1):
            yield from self.home_axes()
            if all(abs(p) <= HOME_TOLERANCE for p in self.position):
                self.get_logger().info('Home reached; Twist enabled')
                return
            details = ', '.join(
                f'{name}={position / TICK_RAD:.0f} ticks'
                for name, position in zip(('pan', 'tilt'), self.position))
            if attempt == HOME_ATTEMPTS:
                raise ValueError(
                    f'An axis moved away from home after {attempt} attempts '
                    f'({details}; tolerance=8 ticks)')
            self.get_logger().warning(
                f'Home drift detected ({details}); '
                f'retrying homing ({attempt + 1}/{HOME_ATTEMPTS})')
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

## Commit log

2026-10-02 Add camera control code and progress notes
2026-10-03 Add(interface): /search 액션, 토픽,QoS 단일 정의(tracking_common)
2026-10-03 Add(perception): target_detector — RealSense 직접/RGBD 구독, HSV·컨투어·뎁스 검증, /target 발행
2026-10-03 Add(control): tracking_controller(팬·틸트, /search), motor_driver(워치독, 출력 OFF)
2026-10-03 Add(bringup): 전체 실행 launch, tracking.yaml, 검증 노드·launch
2026-10-03 Docs: 실행 방법(PC·RPi), 노드 수신·송신 규약, 실측값
2026-10-03 Docs:README.md 수정
2026-10-03 Update: x, y 움직임 명령 동시 적용 코드 작성
2026-10-03 Update: control package
    both x and y simultaneous movement order, speed max 274 deg_s, addition of movement on top of the last position, home position set to 0,0 (north point of motor's front)
2026-10-06 Refactor: 패키지를 역할별 폴더로 이동(인지 xmen_vision, 제어 xmen_control, 통합 xmen_bringup), launch에 카메라 방식 선택 인자(source) 추가
2026-10-06 Docs: 실행·인터페이스 문서를 xmen_bringup으로 이동, RPi 방식 A 빌드 절차와 실측값 추가
2026-10-06 Update: correct file name and add pic folder
    make html file to md
    [main.py]
2026-10-06 Update(interface): 짐벌 속도 명령 토픽을 /cmd_vel로 변경, 문서·주석 반영
2026-10-06 Update: 뎁스와 초점 거리, config값 변경
2026-10-06 Add(control): motor_driver OpenCR 시리얼 연동 — 각속도 전송(V), 현재 각도 수신(P)·/joint_states 발행, 회전 범위 제한
2026-10-06 Refactor: 필요 노드 정리
2026-10-06 add: 큐브 인식 튜닝 추가. evaluate 추가.
2026-10-06 Update: 실습실 실제 환경에서의 밝기 보정, 실측 위치, 실측 depth값 수정
    [detector.yaml]
2026-10-06 add: urdf file and create launch file
    [DYNAMIXEL_XM430_W350_R__Solid_1__DYNAMIXEL_XM430_W350_R__Solid_1.stl, DYNAMIXEL_XM430_W350_R________1__DYNAMIXEL_XM430_W350_R________1.stl, DYNAMIXEL_XM430_W35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]
2026-10-06 Modified: 오검출 및 인식율 튜닝값 적용 및 청색 배경 검출부분 수정
    [detector.yaml]
2026-10-07 add: 문제 1 report.md 추가
2026-10-07 update: hz changed and change limit for motor angle
2026-10-07 add: 문제 3·4 실험 bag·CSV·그래프
    [recovery_events.csv, track_kp1.5_run1_20261006_193326.csv, track_kp1.5_run2_20261006_194917.csv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]
2026-10-07 add: 문제 3·4 보고서 초안 및 검출률 판정 프레임
2026-10-07 update: rviz file and fix control error
    [cctv.urdf]
2026-10-07 update: cube_detector 적용 — 실측 HSV, 실제 크기·모양 검사, 일부 보이는 큐브
2026-10-07 fix: increase motor time delay limit for default value
    [opencr_lite.ino]
2026-10-08 update: cube tracker, CSRT 설정 및 구조 변경
2026-10-08 feat: ros bags 타임스탬프 동기화 수정
2026-10-08 update: add github action for raspberry pi release and updated README.md
2026-10-08 update: change speed cause of overshoot
    [tracker.yaml]
2026-10-08 update: update for problem 3 and 5
    [evaluation_frames.csv]
2026-10-08 refactor: refactor repositories before release
    [evaluation_frames.csv, recovery_events.csv, track_kp1.5_run1_20261006_193326.csv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]
2026-10-08 refactor: update report.md and refactor for submission
    [evaluation_frames.csv, recovery_events.csv, track_kp1.5_run1_20261006_193326.csv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]
